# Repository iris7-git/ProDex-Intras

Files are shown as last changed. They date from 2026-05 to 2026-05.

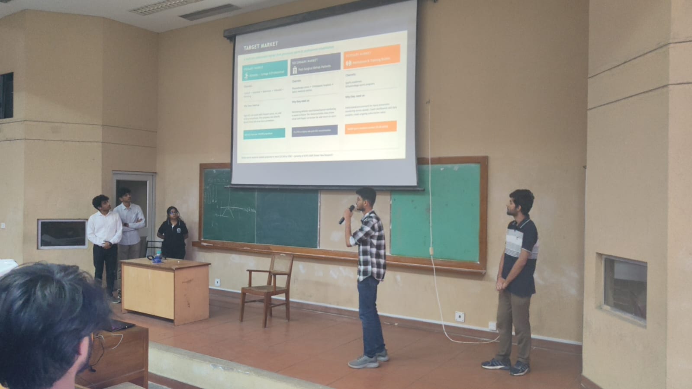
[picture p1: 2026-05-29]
Images/WhatsApp Image 2026-05-28 at 12.59.43 PM (2).jpeg

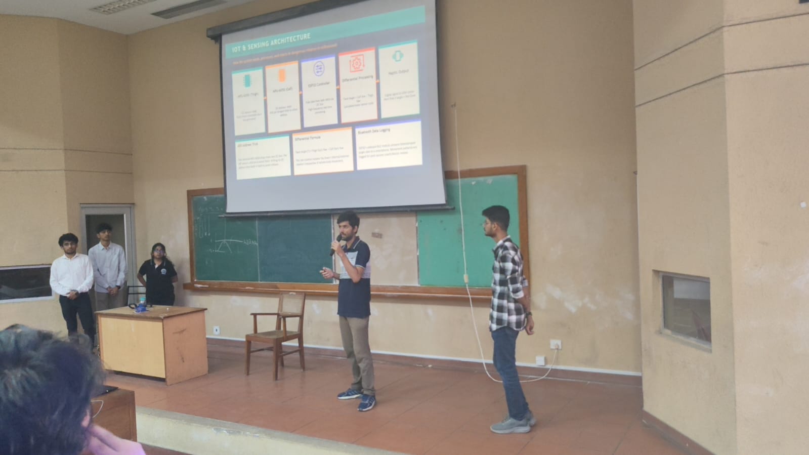
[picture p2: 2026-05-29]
Images/WhatsApp Image 2026-05-28 at 12.59.47 PM (1).jpeg

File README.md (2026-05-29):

# PivotPoint — Real-Time ACL Injury Prevention System

> A smart wearable brace that detects dangerous knee rotation in real-time and delivers instant haptic warnings to prevent ACL injuries before they happen.

---

## The Problem

ACL injuries occur when the knee twists too far, too fast — typically during landings or pivots. The critical issue: **there is no warning**. Standard braces provide mechanical support but cannot detect the hidden rotational torque that causes ligament rupture, leaving athletes moving in high-risk positions with no feedback.

---

## Solution Overview

PivotPoint combines a **mechanical support frame** and an **IoT monitoring system** into a single wearable device.

### Part 1 — Mechanical Frame

An external skeleton that stabilizes the knee joint without restricting natural athletic movement.

| Component | Function |
|---|---|
| **Dual Tapered Cuffs** (Thigh + Calf) | Conform to leg geometry; prevent slipping during dynamic movement |
| **Aluminum Lateral Rods** | Rigid side-rails anchored to thigh and calf cuffs via bolted slots |
| **Sliding-Slot Kinematic Hinge** | Oval vertical slot on calf rod allows free knee flexion while resisting rotational torque |
| **Revolute Lap-Joint at Knee** | Mimics the knee's primary axis of rotation; metal stiffness resists twisting forces |
| **D-Ring Velcro Strap System** | High-compression lock ensuring the frame stays synced with bone movement |

The rods act as **load-sharing partners** — absorbing a portion of rotational torque that would otherwise be borne entirely by the ACL.

### Part 2 — IoT Monitoring System

| Component | Role |
|---|---|
| **ESP32 Microcontroller** | Central processing unit; pulls sensor data and drives outputs |
| **2× MPU-6050 IMU Sensors** | One in thigh cuff, one in calf cuff; track femur vs. tibia orientation |
| **AD0 Address Offset Wiring** | Allows two identical I2C sensors to share one ESP32 bus |
| **ERM Haptic Vibration Motor** | Embedded against skin; fires when a danger threshold is crossed |
| **Bluetooth Module** | Streams movement data wirelessly for logging and analysis |

**Processing pipeline:**
1. ESP32 reads yaw angles from both MPU-6050s at high frequency
2. Computes **Twist Angle** = difference between thigh and calf rotation (differential yaw)
3. If Twist Angle exceeds the **Red Zone threshold (15°–20° internal rotation)** → PWM signal triggers haptic motor
4. Athlete feels sharp vibration → corrects form before ACL reaches failure point

---

## Key Features

- **Real-Time Differential Processing** — Twist angle computed on-device; no cloud dependency
- **Haptic Biofeedback Alert** — Instant tactile warning at the danger threshold
- **Kinematic Sliding-Slot Hinge** — Full knee flexion preserved while rotational torque is resisted
- **Dual-Node IMU Array** — Independent tracking of femur and tibia segments
- **Load-Sharing Frame** — Physically absorbs mechanical stress to reduce ligament load
- **Bluetooth Data Logging** — Transmits biomechanical data to smartphone for coach/doctor review

---

## Hardware & Cost

| Category | Component | Cost (Est.) |
|---|---|---|
| Microcontroller & Sensors | ESP32 + 2× MPU-6050 | ₹800 |
| Haptic Feedback | ERM Coin Vibration Motor + MOSFET Driver | ₹150 |
| Power Supply | 3.7V Li-ion Battery + Slide Switch | ₹100 |
| Wearable Base | Compression Knee Sleeve | ₹450 |
| Structural Frame | PETG / Nylon / CF-PLA Filament (3D Printed) | ₹300 |
| Fasteners | M4 Shoulder Bolts, Nyloc Nuts, M2/M3 Nylon Screws + Jumper Wires | ₹150 |
| **Total** | | **~₹1,950** |

---

## Tech Stack

- **Firmware:** ESP32 (Arduino / ESP-IDF)
- **Sensors:** MPU-6050 (I2C, AD0 address differentiation)
- **Communication:** Bluetooth (data logging to smartphone)
- **Mechanical:** 3D-printed PETG/Nylon cuffs, aluminum rods, lap-joint hinge
- **Feedback:** ERM haptic motor via PWM

---

## References

- [Mechanism of Non-Contact ACL Injuries](https://pmc.ncbi.nlm.nih.gov/articles/PMC8858885/)
- [Tibial Internal Rotation and ACL Risk](https://pmc.ncbi.nlm.nih.gov/articles/PMC10768481/)
- [Knee Flexion Angles and ACL Injuries](https://www.medrxiv.org/content/10.1101/2025.10.20.25338317v1.full.pdf)
- [Real-Time Monitoring System for ACL Injury Prevention](https://www.researchgate.net/publication/385367697_Design_and_Development_of_a_Real-time_Monitoring_System_for_ACL_Injury_Prevention)
- [ESP32 Programming Guide](https://www.raypcb.com/esp32-programming-circuit/)

---

## Future Work

- **ML-Based Predictive Analytics** — Use Bluetooth-logged biomechanical history to build a personalized movement baseline per athlete, enabling prediction of fatigue-driven injury risk *before* the knee enters a danger zone
- Cloud dashboard for coaches and physiotherapists
- Multi-joint support (ankle integration)

---

## Team

| Name |
|---|
| Harshil Mishra |
| Shreesh Tripathi |
| Bhargavi Deo |
| Nandan Krishna S |
| Kamalnath |

*Developed as part of IntraProdex, IIT Kharagpur.*

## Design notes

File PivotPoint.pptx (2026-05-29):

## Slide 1

Pivot point

Real-Time Rotational Torque Detection & Haptic Warning System

ACL

TEAM MEMBERS

Harshil Mishra
Shreesh Tripathi
Bhargavi Deo
Nandan Krishna S
Kamalnath

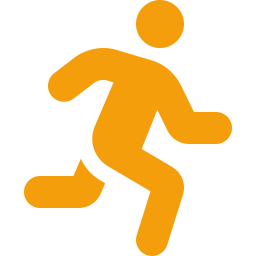
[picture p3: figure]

Intra Prodex

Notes: 1

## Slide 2

PROBLEM STATEMENT

Why are athletes still getting injured despite wearing braces?

How ACL Injuries Happen

  - Knee twists too fast during landing or pivoting
  - Tibial internal rotation exceeds safe threshold
  - Ligament absorbs full torque - then snaps
  - Non-contact injuries are most common (70%+)

The Critical Gap

  - No real-time warning before ligament snaps
  - Twist angle is invisible to the naked eye
  - Traditional braces are purely passive
  - No field-ready monitoring solution exists

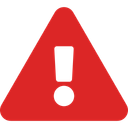
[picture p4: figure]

The Data

  - ₹3–8 Lakh surgery + 9–12 months recovery
  - High recurrence: 15–25% re-injury rate
  - Athletes in football, basketball, badminton most at risk
  - 68.6 ACL tears per 100,000 population in India

Current Braces Are Blind

  - Resist forward movement, not hidden rotation
  - No sensors to detect rotational torque
  - Cannot trigger any warning in real-time

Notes: 2

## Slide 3

RESEARCH & LITERATURE REVIEW

The scientific foundation of our solution

01

Mechanism of Non-Contact ACL Injuries

PMC · 2022

ACL ruptures predominantly occur through tibial internal rotation combined with knee valgus - NOT direct contact. Landing/pivoting biomechanics are the primary culprit.

Insight: Rotation is the root cause.

02

Tibial Internal Rotation & ACL Strain

PMC · 2024

Excessive tibial internal rotation beyond 15°-20° significantly increases ACL loading. This threshold is measurable via differential IMU readings across the joint.

Insight: Gives us our exact Red Zone threshold (15°–20°) for haptic alerts.

03

Knee Flexion Angles & ACL Injury Risk

medRxiv · 2025

ACL injuries peak at low knee flexion angles (< 30°). Athletes land stiff-legged during fatigue, increasing rotational risk. Real-time feedback can correct this.

Insight: Validates need for in-field, real-time monitoring rather than lab analysis.

04

Design of Real-Time ACL Monitoring System

ResearchGate · 2024

IMU-based systems using ESP32 can achieve sub-100ms response latency for joint angle calculations. Differential processing between two sensors is validated as accurate.

Insight: Confirms our ESP32 + dual MPU-6050 architecture is technically feasible.

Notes: 3

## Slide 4

EXISTING SOLUTIONS & THEIR GAPS

Every current solution fails athletes

Solution

What It Does

Critical Limitation

Conclusion

DonJoy / Breg
Functional Braces

Rigid mechanical frame; limits extreme flexion & extension

100% passive - zero sensor data, cannot detect or warn about hidden rotational torque

Blind to rotation

Vicon Optical
Motion Capture

Sub-millimeter 3D tracking of all joint kinematics via camera arrays

Requires lab setup with multiple cameras. Completely unusable on sports fields or clinics

Lab-only, costs lakhs

Smart Compression
Sleeves (e.g. Athos)

Track general metrics (steps, jump height) via embedded single sensors

No rigid support frame - cannot absorb torque. No differential angle processing or haptic alert

No rigid support, no haptics

Our Dynamic
Knee Ankle Support

Dual IMU + rigid frame + real-time differential processing + haptic biofeedback

Currently requires per-athlete calibration.

Field-ready, real-time, way less cost than our competitors

No existing solution combines mechanical support + real-time sensing + haptic alert in a field-deployable, affordable package.

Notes: 4

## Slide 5

OUR SOLUTION - SYSTEM OVERVIEW

A two-part system: physical protection with technological integration

PART 1 - MECHANICAL FRAME

Dual Cuff Frame

Tapered thigh + calf cuffs for secure fit

Aluminum Rods

Lateral rigid rods absorb rotational torque

Revolute Hinge

Lap-joint pin mirrors knee's natural rotation axis

Sliding Slot

Calf rod slot allows free bending, resists twist

Strap System

D-Ring Velcro locks frame to bone movement

PART 2 - IoT MONITORING BRAIN

Dual MPU-6050 IMU Array

One sensor on thigh, one on calf

ESP32 Controller

Pulls data from both IMUs, calculates parameters

Differential Processing

Based on Thigh rotation & Calf rotation

Haptic Alert

ERM motor fires when angle > Red Zone

Bluetooth Logging

Streams movement data to smartphone/coach app

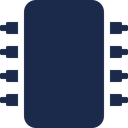
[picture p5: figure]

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
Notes: 5

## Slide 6

MECHANICAL DESIGN

External skeleton engineered to protect without restricting natural athletic movement

Dual Tapered Cuff Frame

Two cuffs (Thigh & Calf) shaped wider at top, narrower at base - mirroring leg anatomy for anti-slip fit. Prevents the brace from sliding during dynamic movement.

Lateral Aluminum Rods

Rigid rods mounted on the lateral (outer) side. Thigh rod fixed via two bolts for a solid femoral anchor. Calf rod secured through a sliding oval slot.

Revolute Hinge (Lap Joint)

Two rods joined at the knee via a lapped pin joint, mimicking the knee's primary flexion axis. Metal stiffness resists the twisting forces that cause ACL tears.

Kinematic Sliding Slot

The calf rod's bolt sits in a vertical oval slot - allows free knee bending (flexion) while maintaining constant lateral and rotational guidance of the lower leg.

D-Ring Velcro Strap System

Loop-back Velcro straps threaded through integrated D-ring slots. Creates high-pressure compression lock ensuring sensors stay perfectly synced with bone movement.

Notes: 6

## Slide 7

IOT & SENSING ARCHITECTURE

How the system reads, processes, and reacts to dangerous rotation in milliseconds

MPU-6050 (Thigh)

I2C Address: 0x68
Tracks femur orientation via 6-axis gyro+accel

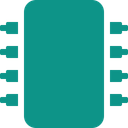
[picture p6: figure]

MPU-6050 (Calf)

I2C Address: 0x69
AD0 pin bridged HIGH to offset address

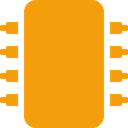
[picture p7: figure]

ESP32 Controller

Pulls data from both IMUs via I2C bus
High-frequency real-time processing

Differential Processing

Twist Angle = Calf Yaw − Thigh Yaw
Calculated every sensor cycle

Haptic Output

Digital signal to ERM motor
Alert fires if angle > Red Zone

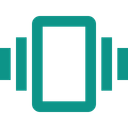
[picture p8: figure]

▶

▶

▶

▶

AD0 Address Trick

Two identical MPU-6050 chips share one I2C bus. The calf sensor's AD0 pin is wired HIGH, shifting its I2C address from 0x68 → 0x69 to avoid collision.

Differential Formula

Twist Angle (°) = Thigh Gyro Yaw − Calf Gyro Yaw
This net rotation isolates the knee's internal/external rotation irrespective of whole-body movement.

Bluetooth Data Logging

ESP32's onboard BLE module streams timestamped angle data to a smartphone. Movement patterns are logged for post-session coach/doctor review.

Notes: 7

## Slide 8

HAPTIC FEEDBACK LOOP

From dangerous angle to corrective warning

SAFE ZONE (0°–15°)

WARNING (15°–20°)

RED ZONE (>20°) - ALERT FIRES

Athlete Pivots

During a landing or cut, the knee begins rotating. Both MPU-6050 sensors capture real-time orientation data independently.

01

ESP32 Calculates Twist Angle

The controller subtracts calf yaw from thigh yaw to compute the exact internal rotation of the knee joint in real time.

02

Red Zone Threshold Crossed

If the differential angle exceeds 15°-20°, the ESP32 identifies a high-risk event. A trigger signal is generated.

03

ERM Motor Fires

The embedded Eccentric Rotating Mass vibration motor activates, delivering a sharp tactile pulse directly against the athlete's skin.

04

Athlete Self-Corrects

The physical sensation is an instant reflex trigger. The athlete adjusts stance or landing mechanics before reaching ligament failure threshold.

05

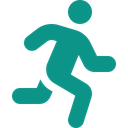
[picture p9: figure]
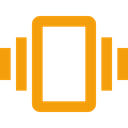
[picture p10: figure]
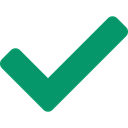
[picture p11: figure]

→

→

→

→

Vibration alert is instantaneous; the athlete feels it before the ligament reaches its mechanical failure point.

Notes: 8

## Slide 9

KEY FEATURES SUMMARY

6 integrated features that set the Dynamic Knee Ankle Support apart

Kinematic Sliding Slot

Oval slot on calf rod, free bending, constant rotational resistance

Dual-Node IMU Array

Two MPU-6050s track femur vs. tibia orientation independently

Real-Time ESP32 Processing

High-frequency on-device computation

Haptic Biofeedback Alert

Instant tactile pulse when knee enters dangerous Red Zone

Load-Sharing Mitigation

Rigid frame absorbs mechanical stress alongside the ligament

Bluetooth Data Logging

Streams movement patterns wirelessly to coach/doctor app

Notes: 9

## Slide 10

COST ANALYSIS

A ₹1,950 solution vs. alternatives

Category

Component

Cost

Cost Comparison vs. Alternatives

Microcontroller & Sensors

ESP32 + 2× MPU-6050 IMU

₹800

Vicon Motion Capture

₹20–50 Lakh

Haptic Feedback

ERM Vibration Motor + Driver

₹150

Power Supply

3.3V Li-ion Battery + Switch

₹100

DonJoy Brace

₹5,000–15,000

Wearable Base

Compression Knee Sleeve

₹450

3D Printed Frame

PETG / Nylon / CF-PLA Filament

₹300

Smart Sleeves

₹3,000–8,000

Mechanical Fasteners

M4 Shoulder Bolts + Nyloc Nuts

₹150

Our Solution

Wiring & Misc

Jumper Wires, connectors

₹0

₹1,950

TOTAL ESTIMATED COST

~₹1,950

At ₹1,950, our device is 2.5–8× cheaper than passive-only braces, and over 1,000× cheaper than lab systems.

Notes: 10

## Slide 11

TARGET MARKET

A multi-tier addressable market from grassroots sports to professional rehabilitation

PRIMARY MARKET

Athletes — College & Professional

Channels:

Football • Basketball • Badminton • Volleyball • Wrestling

Why they need us:

High-ACL-risk sports with frequent pivot, cut, and landing movements. First adopters who directly benefit from real-time injury prevention.

68.6 ACL tears per 100,000 population

SECONDARY MARKET

Post-Surgical Rehab Patients

Channels:

Physiotherapy clinics • Orthopaedic hospitals • Sports medicine centres

Why they need us:

Recovering athletes need biomechanical monitoring to avoid re-injury. Our device provides data-driven rehab with haptic correction for safe return-to-sport.

15–25% re-injury rate post-ACL reconstruction

TERTIARY MARKET

Institutions & Training Bodies

Channels:

Sports academies
School/college sports programs

Why they need us:

Institutional procurement for injury prevention monitoring across squads. Coach dashboards and data analytics create ongoing subscription value.

Global sports medicine market: $9.2B (2024)

Global sports medicine market projected to reach $15.3B by 2030 — growing at 6.5% CAGR (Grand View Research)

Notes: 11

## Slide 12

RISKS & LIMITATIONS

Transparent risk assessment - and our mitigation roadmap for each

Sensor Drift Over Time

Gyroscope bias accumulates → angle readings become inaccurate after extended use.

Periodic re-calibration protocol + drift-correction algorithm in firmware.

Risk:

Comfort

Rigid frame may cause discomfort in long matches; athletes may remove brace.

Comfortable padding, lightweight materials, comfort-testing iterations.

Risk:

Per-Athlete Calibration

Each user requires individual calibration for accurate Red Zone thresholds.

Auto-calibration routine on first use; ML-based adaptive baseline.

Risk:

Mitigation:

Mitigation:

Mitigation:

Not a Medical Replacement

Device is a warning system — cannot prevent all injuries or replace clinical assessment.

Clear usage guidelines + medical professional integration in dashboard.

Regulatory Pathway

Medical device clearance required before clinical or commercial deployment.

Plan: Start as sports training aid

Battery Life Constraints

3.3V Li-ion battery limits continuous operation — replacement/recharging during matches.

Low-power ESP32 sleep modes; wireless charging coil integration planned.

Risk:

Risk:

Risk:

Mitigation:

Mitigation:

Mitigation:

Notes: 12

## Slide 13

FUTURE PROSPECTS

The roadmap from prototype to AI-powered sports safety platform

ML & Predictive Analytics

Leveraging Bluetooth-logged biomechanical data, machine learning models will learn each athlete's unique movement patterns and establish personalized baselines. The system will predict fatigue-related injury risk BEFORE kinematics enter the danger zone.

Personalized Fatigue-Risk Baselines

Each athlete's 'normal' rotation profile varies. Adaptive calibration will auto-adjust Red Zone thresholds based on individual biomechanics, sport type, and real-time fatigue levels detected from gait pattern degradation.

ML on ESP32

Anomaly detection

Long-term pattern learning

Adaptive thresholds

Fatigue modelling

Sport-specific profiles

Miniaturisation & Wireless Charging

Replacing current components with miniaturized alternatives and integrating a wireless charging coil will reduce device weight by 40%+. Form factor will shrink to a discreet sensor patch worn beneath athletic gear.

Coach & Doctor Dashboard App

A cross-platform mobile/web app providing coaches and physiotherapists with real-time biomechanical dashboards, session reports, injury risk heatmaps, and long-term trend analysis for entire squads.

miniaturization

wireless charging

Sub weight

App

Squad analytics

Injury risk heatmaps

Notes: 13

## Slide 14

THANK YOU

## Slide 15

APPENDIX - Circuit Diagram & Visual representation

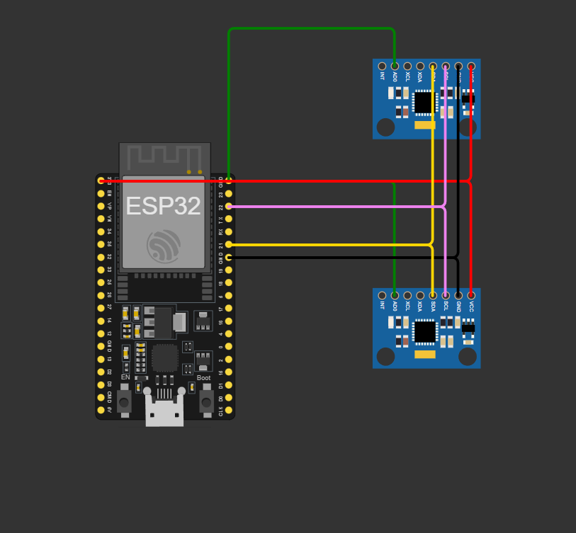
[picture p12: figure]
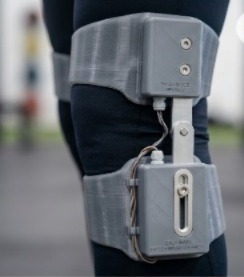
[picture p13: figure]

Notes: 14

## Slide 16

APPENDIX – CAD & References

Mechanism of non contact ACL injuries (https://pmc.ncbi.nlm.nih.gov/articles/PMC8858885/)
PMC · 2022
Tibial internal rotation (https://pmc.ncbi.nlm.nih.gov/articles/PMC10768481/)
PMC · 2024
Relation of (https://www.medrxiv.org/content/10.1101/2025.10.20.25338317v1.full.pdf)Kneeflexion (https://www.medrxiv.org/content/10.1101/2025.10.20.25338317v1.full.pdf) angles with ACL injuries (https://www.medrxiv.org/content/10.1101/2025.10.20.25338317v1.full.pdf)
medRxiv · 2025
Design and Development of a Real-time Monitoring System for ACL Injury Prevention (https://www.researchgate.net/publication/385367697_Design_and_Development_of_a_Real-time_Monitoring_System_for_ACL_Injury_Prevention)
ResearchGate · 2024
ESP32 programming guide (https://www.raypcb.com/esp32-programming-circuit/)

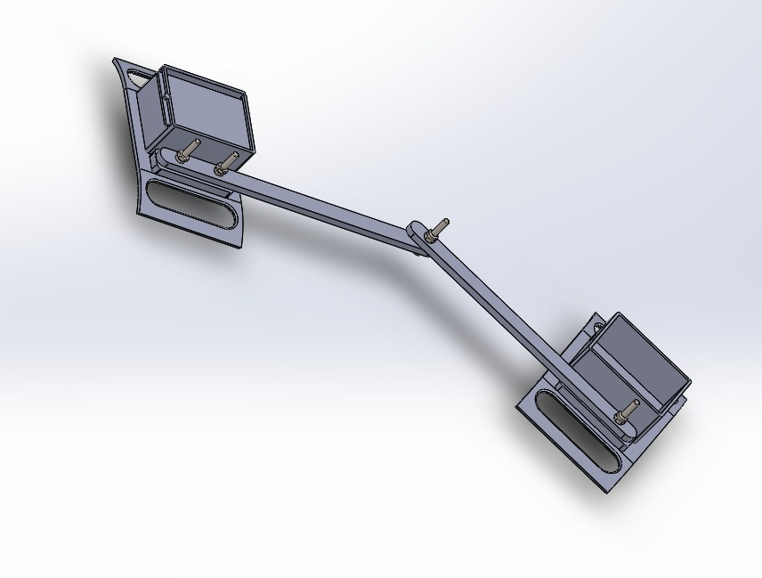
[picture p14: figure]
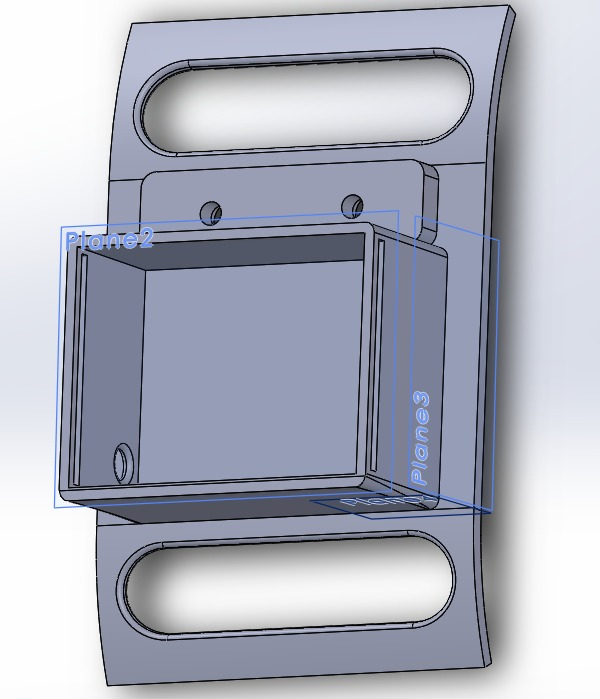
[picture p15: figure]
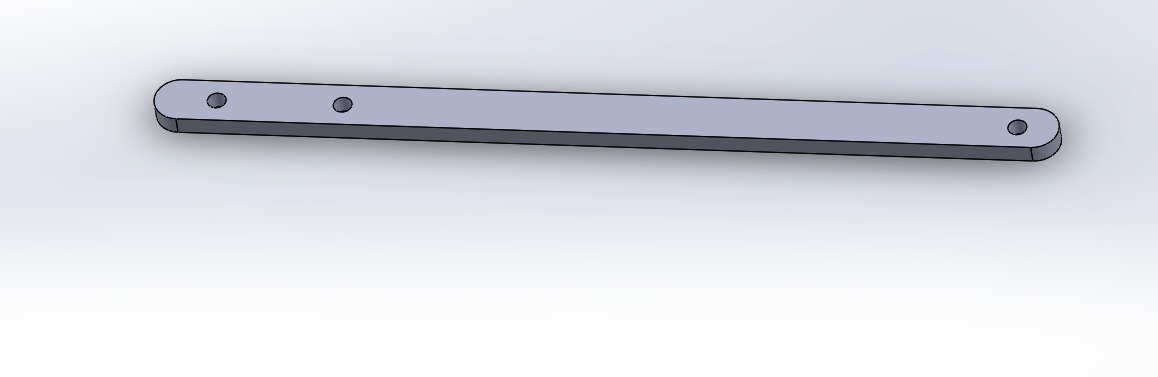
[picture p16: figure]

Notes: 15

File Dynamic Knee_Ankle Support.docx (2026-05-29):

# PivotPoint

## Team Members

- Harshil Mishra
- Shreesh Tripathi
- Bhargavi Deo
- Nandan Krishna S
- Kamalnath

# Understanding of the Problem

ACL(Anterior Cruciate Ligament) injuries usually happen when the knee twists too far and too fast while an athlete is landing or turning. Right now, there is no way for a person to know if their leg is twisting at a dangerous angle until the ligament actually snaps. Standard knee braces can hold the leg straight, but they cannot measure or see the hidden twist that causes the most damage. This leaves athletes moving in high-risk ways without any warning or data to stop an injury before it happens

## Relevant Literature

Mechanism of non contact ACL injuries (https://pmc.ncbi.nlm.nih.gov/articles/PMC8858885/)

Tibial internal rotation (https://pmc.ncbi.nlm.nih.gov/articles/PMC10768481/)

Relation of Kneeflexion angles with ACL injuries (https://www.medrxiv.org/content/10.1101/2025.10.20.25338317v1.full.pdf)

Design and Development of a Real-time Monitoring System for ACL Injury Prevention (https://www.researchgate.net/publication/385367697_Design_and_Development_of_a_Real-time_Monitoring_System_for_ACL_Injury_Prevention)

ESP32 programming guide (https://www.raypcb.com/esp32-programming-circuit/)

## Existing Solutions

1. Traditional Prophylactic/Functional Braces (e.g., DonJoy, Breg):

- Drawback: These are entirely passive, relying solely on rigid mechanical structures to restrict or lock movement.
- Result: While they offer lateral stability, they cannot measure hidden twisting forces, dynamically warn the user, and ultimately can only resist force until the point of mechanical failure.

2. Optical Motion Capture Systems (e.g., Vicon):

- Drawback: These systems require multiple cameras and post-processing, confining them strictly to laboratory settings and their cost is over the roof.
- Result: Although they provide sub-millimeter tracking of knee kinematics, they are useless for real-time field applications or live injury mitigation.

3. Smart Compression Sleeves:

- Drawback: These modern wearables track general metrics (like step count or jump height) with single sensors but crucially lack a rigid mechanical support frame needed to absorb rotational torque.
- Result: They cannot process differential joint angles to trigger the instant haptic warnings required for effective injury prevention.

# Proposed Solution

The Proposed Solution consists of two parts:

### Part 1: The Mechanical Part (The Support and Mitigation Frame) -

The hardware is designed to act as an external skeleton that stabilizes the joint without restricting natural athletic movement.
a) Supportive Mitigation: The rigid rods are not intended to lock the knee in a frozen position. Instead, they provide a support system that absorbs a portion of the rotational torque that would otherwise be handled entirely by the ACL. By sharing the load between the metal frame and the ligament, the system reduces the overall risk of a rupture during high-stress maneuvers.

b) Dual-Cuff Frame: The system uses two tapered cuffs (Thigh and Calf). Both are wider at the top and narrower at the bottom to match the leg’s natural shape. This ensures the brace doesn't slip down, keeping the support structure aligned with the knee joint at all times.

c)The Aluminum Sticks: Rigid aluminum rods are mounted on the outside (lateral side) of the leg.

- Thigh Side: The rod is fixed with two bolts into the thigh box. This creates a solid anchor point against the femur.
- Calf Side: The rod is secured by a bolt sitting in a vertical sliding slot. This allows the leg to bend (flexion) while the rod provides lateral and rotational guidance to the lower leg.

d) The Revolute Hinge: The two rods are joined at the knee using a lap joint (two sticks pinned together). This mimic's the knee's primary axis of rotation while the metal's stiffness resists the twisting forces that lead to injury.

e) Strap System (to connect cuff with leg): Each cuff uses D-Ring Velcro straps threaded through integrated slots. This creates a high-pressure lock to the limb, ensuring the mechanical frame and the sensors stay perfectly synced with the athlete's bones.

### Part 2: The IoT System (The Monitoring & Warning Brain)

a) Two Sensors used - Two IMU (Inertial Measurement Unit) Sensors are used. One is placed inside the rectangular hollow box in the thigh cuff and the other in the calf cuff.

b) Real-Time Differential Processing: The ESP32 pulls data from both sensors. It calculates the Twist Angle (the difference between the thigh and calf rotation).

c) Haptic Biofeedback: A small ERM (Eccentric Rotating Mass) haptic motor is embedded inside the cuff, sitting directly against the athlete's skin.

- The Trigger: When the ESP32 detects that the rotational torque or angle is entering a Red Zone (e.g., above 15°–20° of internal rotation), it sends a PWM signal to the motor.
- The Result: The athlete feels a sharp vibration on their leg. This instant physical cue tells them to adjust their landing or pivot, allowing them to correct their form before the ligament reaches its breaking point.

## Key Features of the Proposed Model:

1. Kinematic Sliding-Slot Hinge: Features a vertical oval slot on the calf rod to allow free knee bending while maintaining constant lateral and rotational support.
2. D-Ring Strapping: Utilizes a loop-back Velcro system through integrated slots to provide maximum compression and "lock" the sensors to bone movement.
3. Dual-Node IMU Array: Integrates two MPU-6050 sensors to track the orientation of the femur versus the tibia for precise twist-angle calculation.
4. AD0 Address Offset: Uses a custom wiring bridge on the calf sensor's AD0 pin to allow two identical I2C devices to communicate with one ESP32.
5. Real-Time ESP32 Processing: Processes high-frequency movement data internally to detect sudden, high-risk pivots or landing impacts as they happen.
6. Haptic Biofeedback Alert: Triggers an embedded vibration motor to provide an instant tactile warning when the knee enters a dangerous rotational "Red Zone."
7. Load-Sharing Risk Mitigation: Acts as a physical safety net that absorbs a portion of the mechanical stress to reduce the risk of ligament failure.
8. Bluetooth Data Logging: Transmits movement patterns wirelessly to a smartphone for long-term biomechanical analysis by coaches or doctors.

## Cost Analysis of our product:

Category | Component | Estimated cost
Microcontroller & Sensors | ESP32 Microcontroller | ₹ 800
| MPU-6050 IMU Sensors (2 units)
Haptic Feedback | 10mm Flat Coin Vibration Motor | ₹ 150
| Vibration Motor Driver Module (MOSFET type)
Power Supply | 3.7V Li ion Battery (Rechargeable) | ₹ 100
| Mini SPDT Slide Switch
Wearable Base & Comfort | Compression Knee Sleeve | ₹ 450
Structural Frame (3D Printed) | High-Strength Filament (PETG, Nylon, or CF PLA) | ₹ 300
Mechanical Fasteners | M4 Steel Shoulder Bolts and Nyloc Nuts | ₹ 150
| M2/M3 Nylon Screws
Wiring | Jumper Wires
Total Estimated Cost | | ~ ₹ 1,950

## Future Prospects:

Machine Learning and Predictive Analytics:

Leveraging the system's current Bluetooth data logging functionality, future development will incorporate machine learning and predictive analytics. These algorithms will process extensive historical biomechanical data to analyze an athlete's unique long-term movement patterns, thereby establishing a personalized baseline. This will enable the system to anticipate and predict fatigue-related injury risks before the kinematics deviate into an immediate danger zone.

## Diagram:

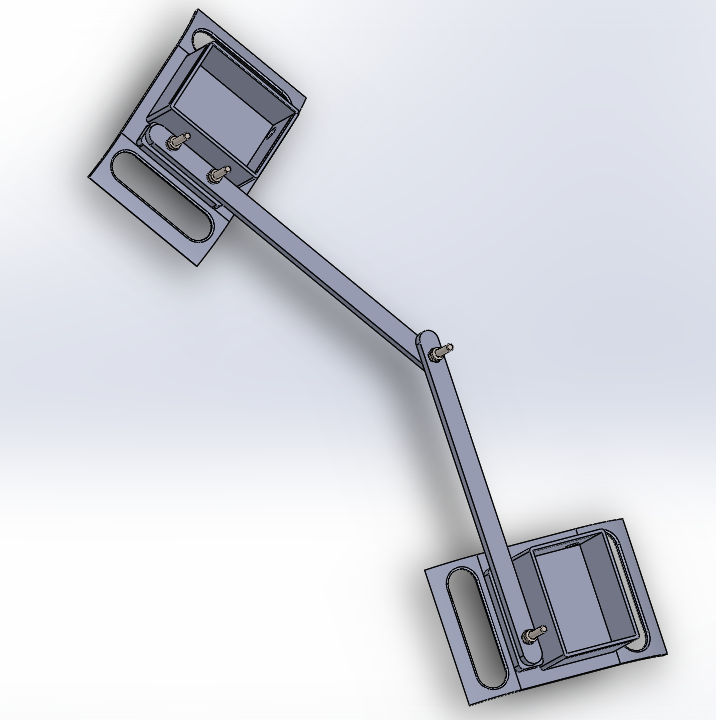
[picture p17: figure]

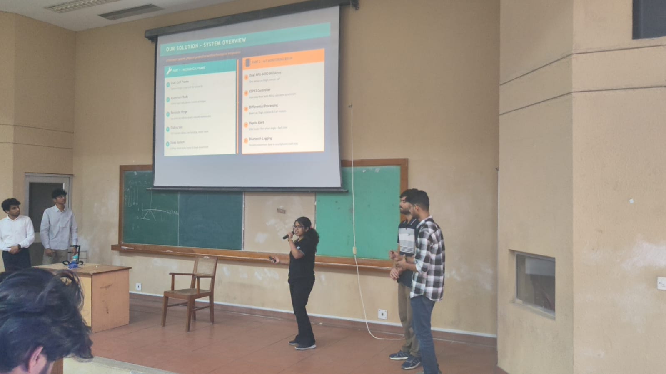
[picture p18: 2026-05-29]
Images/WhatsApp Image 2026-05-28 at 12.59.48 PM.jpeg

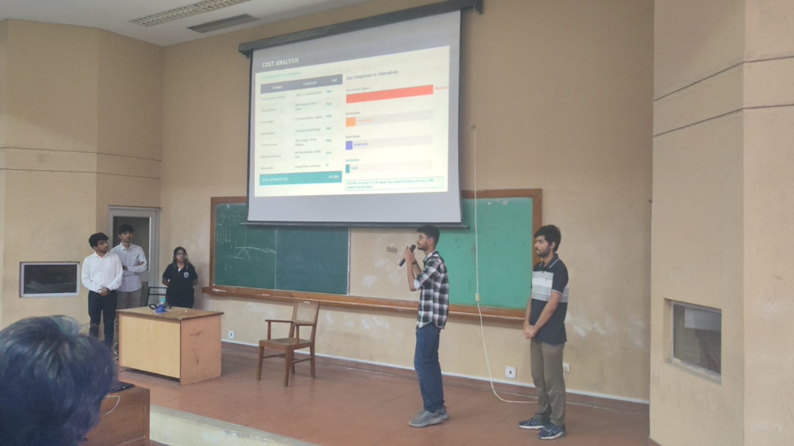
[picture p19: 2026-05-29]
Images/WhatsApp Image 2026-05-28 at 12.59.46 PM.jpeg

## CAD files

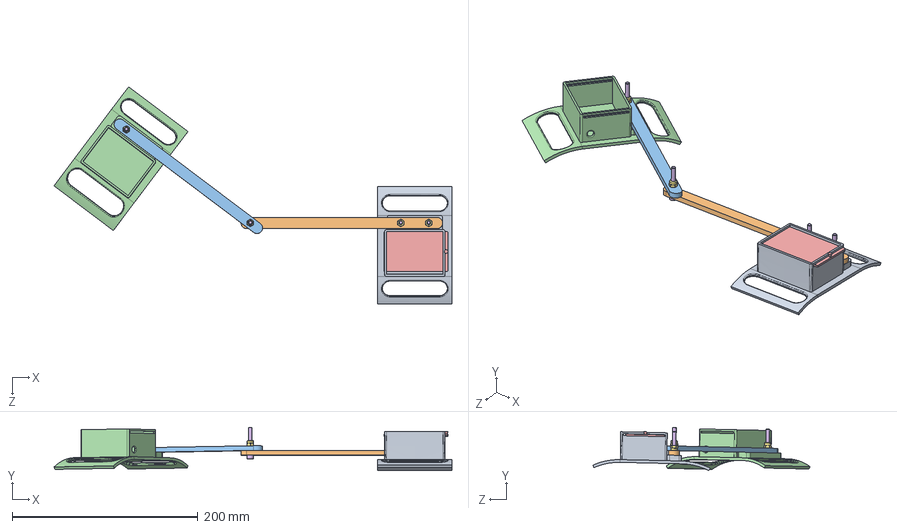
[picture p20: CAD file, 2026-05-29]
Assem3.SLDASM
428.3 x 46.6 x 233.9 mm
Thigh Box
Thigh Rod
Calf Rod
Calf Box
Lid for calf box and thigh box
socket head cap screw_iso-final x 4
torque nut 01_iso x 4

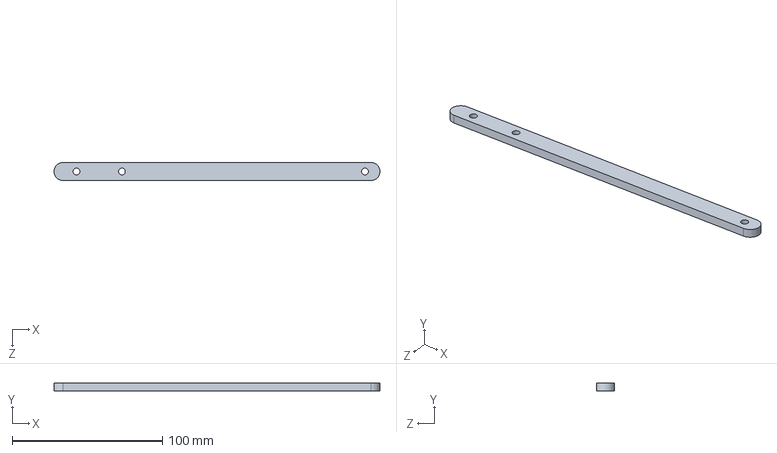
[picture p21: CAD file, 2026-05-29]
CAD Assembly Parts/Thigh Rod.SLDPRT
216.9 x 5.00 x 12.0 mm

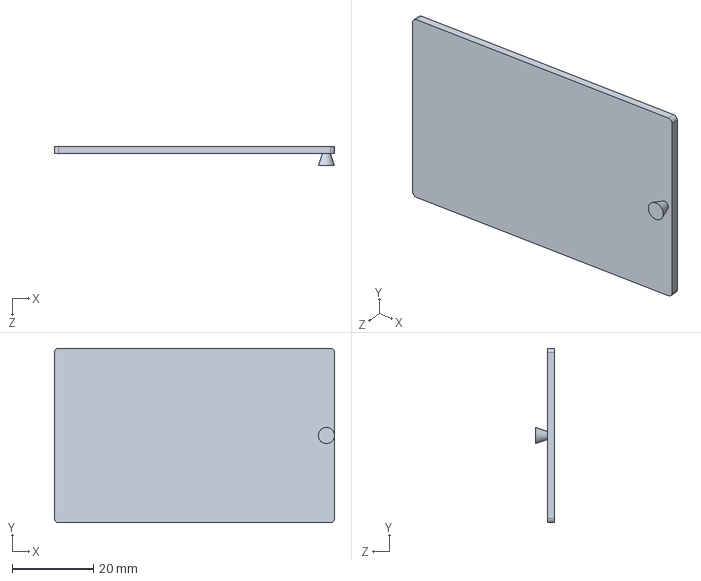
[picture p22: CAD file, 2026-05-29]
CAD Assembly Parts/Lid for calf box and thigh box.SLDPRT
69.0 x 43.0 x 4.80 mm

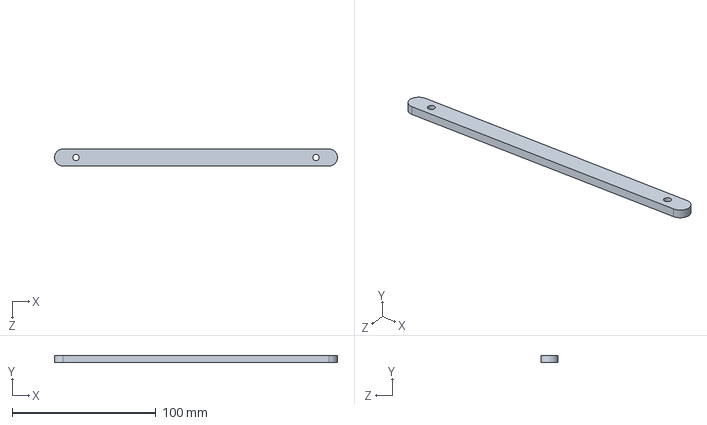
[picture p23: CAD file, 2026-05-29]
CAD Assembly Parts/Calf Rod.SLDPRT
197.0 x 5.00 x 12.0 mm

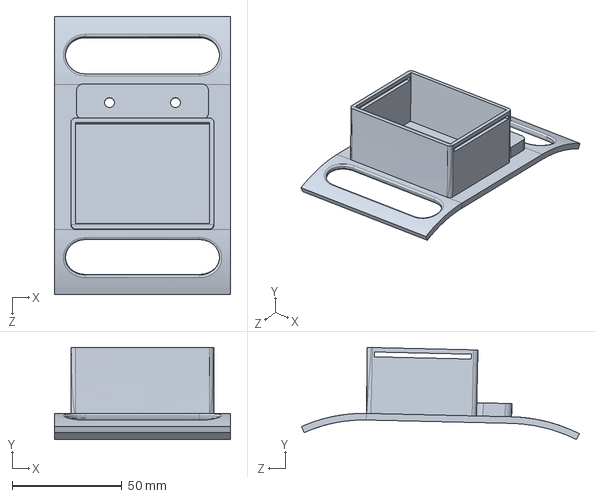
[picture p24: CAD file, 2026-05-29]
CAD Assembly Parts/Thigh Box.SLDPRT
80.0 x 41.9 x 126.4 mm

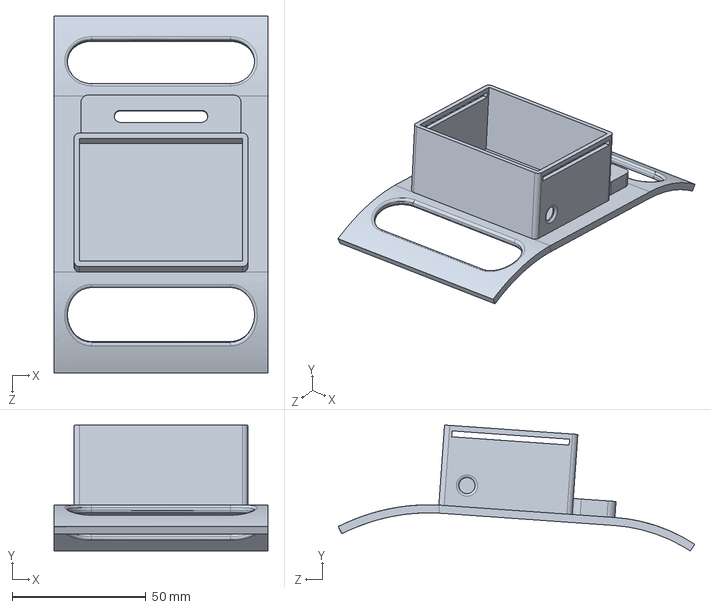
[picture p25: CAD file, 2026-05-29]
CAD Assembly Parts/Calf Box.SLDPRT
80.0 x 47.1 x 133.3 mm

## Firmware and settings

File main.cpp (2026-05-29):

#include <Wire.h>
#include <Adafruit_MPU6050.h>
#include <Adafruit_Sensor.h>
#include <WiFi.h>
#include <WebServer.h>

// ---------------------------------------------------------
// HARDWARE SETTINGS
// ---------------------------------------------------------
#define MOTOR_PIN 15

// ---------------------------------------------------------
// WIFI SETTINGS
// Set these to your phone hotspot credentials.
// After boot, Serial prints the IP — open it in any browser.
// ---------------------------------------------------------
const char* WIFI_SSID     = "IQOO Z10X";
const char* WIFI_PASSWORD = "iznhkdj94reqtzm";

// ---------------------------------------------------------
// CALIBRATION SETTINGS
// ---------------------------------------------------------
#define CALIB_DURATION_MS        3000
#define CALIB_SAMPLE_INTERVAL_MS 10

// ---------------------------------------------------------
// THRESHOLDS — 3 zones per metric
// YELLOW = warning (approaching danger)
// RED    = alert (dangerous, haptic fires)
// ---------------------------------------------------------

// Knee Flexion/Extension
const float HYPEREXTENSION_RED    = -5.0;   // degrees
const float FLEXION_YELLOW        = 110.0;  // degrees
const float FLEXION_RED           = 130.0;  // degrees

// Valgus Wobble
const float WOBBLE_YELLOW         = 10.0;   // degrees
const float WOBBLE_RED            = 15.0;   // degrees

// Tibial Twist
const float TWIST_YELLOW          = 12.0;   // degrees
const float TWIST_RED             = 20.0;   // degrees

// Hard Landing
const float IMPACT_RED            = 29.4;   // m/s² net (~3G)

// Combined mechanics — all three at medium threshold = critical
const float COMBO_ANGLE_THRESH    = 20.0;
const float COMBO_WOBBLE_THRESH   = 8.0;
const float COMBO_TWIST_THRESH    = 10.0;

// ---------------------------------------------------------
// SIDE-MOUNT AXIS NOTE
// MPUs mounted on the SIDE of thigh and shin:
//   Knee Flexion/Extension -> gyro.y / accel Y-axis
//   Valgus/Varus Wobble    -> gyro.x / accel X-axis
//   Tibial Twist (Yaw)     -> gyro.z
// Swap gyro.x <-> gyro.y if physical test shows mismatch.
// ---------------------------------------------------------

// ---------------------------------------------------------
// WiFi / WEB SERVER GLOBALS
// ---------------------------------------------------------
WebServer server(80);

// Simple ring buffer to store last 30 alert events
// Each entry is a plain string — readable in the browser
#define MAX_LOG_ENTRIES 30
String  alertLog[MAX_LOG_ENTRIES];
int     logHead    = 0;   // points to next write position
int     logCount   = 0;   // total entries written so far
unsigned long alertCounter = 0;

// ---------------------------------------------------------
// IMU & FILTER GLOBALS
// ---------------------------------------------------------
Adafruit_MPU6050 thighIMU;
Adafruit_MPU6050 calfIMU;

unsigned long lastTime = 0;
float alpha = 0.98;

float thighPitch = 0, thighRoll = 0;
float calfPitch  = 0, calfRoll  = 0;
float relTwist   = 0;

float biasPitchThigh = 0, biasRollThigh = 0;
float biasPitchCalf  = 0, biasRollCalf  = 0;
float biasGyroZ      = 0;

// ---------------------------------------------------------
// FUNCTION DECLARATIONS
// ---------------------------------------------------------
void triggerHaptic(int pattern);
void calibrate();
void setupWiFi();
void setupWebServer();
void logAlert(const char* zone, const char* alertType,
              float angle, float wobble,
              float twist, float impact);

// ---------------------------------------------------------
// WEB PAGE
// Auto-refreshes every 3 seconds.
// Shows all stored alert events in a clean table.
// ---------------------------------------------------------
void handleRoot() {
  String html = R"rawhtml(
<!DOCTYPE html><html><head>
<meta charset='UTF-8'>
<meta http-equiv='refresh' content='3'>
<meta name='viewport' content='width=device-width, initial-scale=1'>
<title>ACL Brace Monitor</title>
<style>
  body { font-family: monospace; background: #0d0d0d; color: #e0e0e0; padding: 16px; }
  h2   { color: #00e5ff; margin-bottom: 4px; }
  p    { color: #888; font-size: 12px; margin-top: 0; }
  table { width: 100%; border-collapse: collapse; font-size: 13px; }
  th   { background: #1a1a1a; color: #00e5ff; padding: 8px; text-align: left; }
  td   { padding: 7px 8px; border-bottom: 1px solid #222; }
  .CRITICAL { color: #ff1744; font-weight: bold; }
  .RED      { color: #ff6d00; }
  .YELLOW   { color: #ffd600; }
  .empty    { color: #555; text-align: center; padding: 24px; }
</style>
</head><body>
<h2>ACL Brace — Alert Log</h2>
<p>Auto-refreshes every 3 seconds &nbsp;|&nbsp; )rawhtml";

  html += String(logCount) + " event(s) recorded</p>";
  html += "<table><tr><th>#</th><th>Zone</th><th>Type</th>"
          "<th>Angle</th><th>Wobble</th><th>Twist</th><th>Impact</th><th>Time(s)</th></tr>";

  if (logCount == 0) {
    html += "<tr><td colspan='8' class='empty'>No alerts yet — system monitoring...</td></tr>";
  } else {
    // Print newest first
    int entries = min(logCount, MAX_LOG_ENTRIES);
    for (int i = 0; i < entries; i++) {
      int idx = (logHead - 1 - i + MAX_LOG_ENTRIES) % MAX_LOG_ENTRIES;
      html += alertLog[idx];
    }
  }

  html += "</table></body></html>";
  server.send(200, "text/html", html);
}

// ---------------------------------------------------------
// SETUP
// ---------------------------------------------------------
void setup() {
  Serial.begin(115200);
  delay(2000);

  pinMode(MOTOR_PIN, OUTPUT);
  digitalWrite(MOTOR_PIN, LOW);

  Serial.println("\n--- Smart ACL Brace: Full Kinematics + WiFi Mode ---");

  // --- Step 1: IMUs ---
  Wire.begin(21, 22);
  Wire.setClock(100000);
  Wire.setTimeOut(150);

  Serial.println("Checking Thigh Sensor (0x68)...");
  if (!thighIMU.begin(0x68)) {
    Serial.println("CRITICAL ERROR: Thigh MPU6050 not found. HALTING.");
    while (true) { delay(1000); }
  }
  Serial.println("Thigh Sensor OK!");

  Serial.println("Checking Calf Sensor (0x69)...");
  if (!calfIMU.begin(0x69)) {
    Serial.println("CRITICAL ERROR: Calf MPU6050 not found. Is AD0 on 3.3V? HALTING.");
    while (true) { delay(1000); }
  }
  Serial.println("Calf Sensor OK!");

  thighIMU.setAccelerometerRange(MPU6050_RANGE_8_G);
  thighIMU.setGyroRange(MPU6050_RANGE_500_DEG);
  calfIMU.setAccelerometerRange(MPU6050_RANGE_8_G);
  calfIMU.setGyroRange(MPU6050_RANGE_500_DEG);

  // --- Step 2: WiFi + Web Server ---
  setupWiFi();
  setupWebServer();

  // --- Step 3: Calibrate ---
  triggerHaptic(5); // 2 short buzzes: "hold still"

  Serial.print("Calibrating for ");
  Serial.print(CALIB_DURATION_MS / 1000);
  Serial.println(" seconds... Hold still in neutral stance.");

  calibrate();

  triggerHaptic(1); // 1 long buzz: "done, go"
  Serial.println("System Running.");
  Serial.println("----------------------------------------------------");

  lastTime = millis();
}

// ---------------------------------------------------------
// WIFI SETUP
// ---------------------------------------------------------
void setupWiFi() {
  Serial.print("[WiFi] Connecting to ");
  Serial.print(WIFI_SSID);

  WiFi.begin(WIFI_SSID, WIFI_PASSWORD);

  int attempts = 0;
  while (WiFi.status() != WL_CONNECTED && attempts < 20) {
    delay(500);
    Serial.print(".");
    attempts++;
  }

  if (WiFi.status() == WL_CONNECTED) {
    Serial.println("\n[WiFi] Connected!");
    Serial.print("[WiFi] Open this in your browser: http://");
    Serial.println(WiFi.localIP());
  } else {
    // WiFi failed — system still works, just no remote logging
    Serial.println("\n[WiFi] Could not connect. Running Serial-only mode.");
  }
}

// ---------------------------------------------------------
// WEB SERVER SETUP
// ---------------------------------------------------------
void setupWebServer() {
  server.on("/", handleRoot);
  server.begin();
  Serial.println("[Web] Server started on port 80.");
}

// ---------------------------------------------------------
// LOG ALERT
// Stores event in ring buffer AND prints to Serial.
// Zone is "YELLOW" or "RED" or "CRITICAL".
// ---------------------------------------------------------
void logAlert(const char* zone, const char* alertType,
              float angle, float wobble,
              float twist, float impact) {
  alertCounter++;
  float timestamp = millis() / 1000.0;

  // Serial log
  Serial.printf("[%s] #%lu %s | Angle:%.1f Wobble:%.1f Twist:%.1f Impact:%.1f t=%.1fs\n",
    zone, alertCounter, alertType, angle, wobble, twist, impact, timestamp);

  // Build HTML table row for web page
  String row = "<tr class='";
  row += zone;
  row += "'><td>";
  row += alertCounter;
  row += "</td><td>";
  row += zone;
  row += "</td><td>";
  row += alertType;
  row += "</td><td>";
  row += String(angle, 1);
  row += "°</td><td>";
  row += String(wobble, 1);
  row += "°</td><td>";
  row += String(twist, 1);
  row += "°</td><td>";
  row += String(impact, 1);
  row += " m/s²</td><td>";
  row += String(timestamp, 1);
  row += "s</td></tr>";

  // Write to ring buffer
  alertLog[logHead] = row;
  logHead = (logHead + 1) % MAX_LOG_ENTRIES;
  logCount++;
}

// ---------------------------------------------------------
// CALIBRATION
// ---------------------------------------------------------
void calibrate() {
  float accumPitchThigh = 0, accumRollThigh = 0;
  float accumPitchCalf  = 0, accumRollCalf  = 0;
  float accumGyroZ      = 0;
  int   samples         = 0;

  unsigned long calibStart = millis();

  while (millis() - calibStart < CALIB_DURATION_MS) {
    sensors_event_t t_a, t_g, t_temp;
    sensors_event_t c_a, c_g, c_temp;
    thighIMU.getEvent(&t_a, &t_g, &t_temp);
    calfIMU.getEvent(&c_a, &c_g, &c_temp);

    accumPitchThigh += atan2(t_a.acceleration.y, sqrt(pow(t_a.acceleration.x, 2) + pow(t_a.acceleration.z, 2))) * 180.0 / PI;
    accumRollThigh  += atan2(-t_a.acceleration.x, t_a.acceleration.z) * 180.0 / PI;
    accumPitchCalf  += atan2(c_a.acceleration.y, sqrt(pow(c_a.acceleration.x, 2) + pow(c_a.acceleration.z, 2))) * 180.0 / PI;
    accumRollCalf   += atan2(-c_a.acceleration.x, c_a.acceleration.z) * 180.0 / PI;
    accumGyroZ      += (c_g.gyro.z - t_g.gyro.z) * 180.0 / PI;

    samples++;
    delay(CALIB_SAMPLE_INTERVAL_MS);
  }

  biasPitchThigh = accumPitchThigh / samples;
  biasRollThigh  = accumRollThigh  / samples;
  biasPitchCalf  = accumPitchCalf  / samples;
  biasRollCalf   = accumRollCalf   / samples;
  biasGyroZ      = accumGyroZ      / samples;

  thighPitch = biasPitchThigh;
  thighRoll  = biasRollThigh;
  calfPitch  = biasPitchCalf;
  calfRoll   = biasRollCalf;
  relTwist   = 0;

  Serial.print("Bias | thighPitch: "); Serial.print(biasPitchThigh, 2);
  Serial.print("  calfPitch: ");       Serial.print(biasPitchCalf,  2);
  Serial.print("  gyroZ-diff: ");      Serial.print(biasGyroZ,      3);
  Serial.println(" deg/s");

  lastTime = millis();
}

// ---------------------------------------------------------
// MAIN LOOP
// ---------------------------------------------------------
void loop() {
  // Handle incoming web requests (non-blocking)
  server.handleClient();

  // 1. Time Delta
  unsigned long currentTime = millis();
  float dt = (currentTime - lastTime) / 1000.0;
  lastTime = currentTime;

  // 2. Read both sensors
  sensors_event_t t_a, t_g, t_temp;
  sensors_event_t c_a, c_g, c_temp;
  thighIMU.getEvent(&t_a, &t_g, &t_temp);
  calfIMU.getEvent(&c_a, &c_g, &c_temp);

  // 3. Accelerometer tilt (side-mount: Y-axis = knee flexion)
  float t_accelPitch = atan2(t_a.acceleration.y, sqrt(pow(t_a.acceleration.x, 2) + pow(t_a.acceleration.z, 2))) * 180.0 / PI;
  float t_accelRoll  = atan2(-t_a.acceleration.x, t_a.acceleration.z) * 180.0 / PI;
  float c_accelPitch = atan2(c_a.acceleration.y, sqrt(pow(c_a.acceleration.x, 2) + pow(c_a.acceleration.z, 2))) * 180.0 / PI;
  float c_accelRoll  = atan2(-c_a.acceleration.x, c_a.acceleration.z) * 180.0 / PI;

  // 4. Complementary Filter
  thighPitch = alpha * (thighPitch + (t_g.gyro.y * 180.0 / PI) * dt) + (1 - alpha) * t_accelPitch;
  thighRoll  = alpha * (thighRoll  + (t_g.gyro.x * 180.0 / PI) * dt) + (1 - alpha) * t_accelRoll;
  calfPitch  = alpha * (calfPitch  + (c_g.gyro.y * 180.0 / PI) * dt) + (1 - alpha) * c_accelPitch;
  calfRoll   = alpha * (calfRoll   + (c_g.gyro.x * 180.0 / PI) * dt) + (1 - alpha) * c_accelRoll;

  // 5. Relative Tibial Twist — bias-corrected
  float gyroZDelta = ((c_g.gyro.z - t_g.gyro.z) * 180.0 / PI) - biasGyroZ;
  relTwist += gyroZDelta * dt;

  // 6. Kinematic Metrics — relative to calibrated neutral
  float kneeAngle   = (thighPitch - biasPitchThigh) - (calfPitch - biasPitchCalf);
  float wobbleIndex = abs((thighRoll - biasRollThigh) - (calfRoll - biasRollCalf));
  float twistIndex  = abs(relTwist);
  float verticalImpact = abs(c_a.acceleration.z) - 9.8;

  // 7. Danger Logic — CRITICAL > RED > YELLOW, ordered by severity
  bool danger = false;

  // --- CRITICAL: All three mechanisms at once ---
  if (kneeAngle   > COMBO_ANGLE_THRESH &&
      wobbleIndex > COMBO_WOBBLE_THRESH &&
      twistIndex  > COMBO_TWIST_THRESH) {
    Serial.print(">>> CRITICAL: Combined ACL Mechanism! <<<  ");
    logAlert("CRITICAL", "COMBINED", kneeAngle, wobbleIndex, twistIndex, verticalImpact);
    triggerHaptic(4);
    danger = true;
  }

  // --- RED ZONE alerts (haptic fires) ---
  else if (verticalImpact > IMPACT_RED && kneeAngle > 5.0) {
    Serial.print(">>> RED: Hard Landing! <<<  ");
    logAlert("RED", "HARD_LANDING", kneeAngle, wobbleIndex, twistIndex, verticalImpact);
    triggerHaptic(1);
    danger = true;
  }
  else if (kneeAngle < HYPEREXTENSION_RED) {
    Serial.print(">>> RED: Hyperextension! <<<  ");
    logAlert("RED", "HYPEREXTENSION", kneeAngle, wobbleIndex, twistIndex, verticalImpact);
    triggerHaptic(1);
    danger = true;
  }
  else if (kneeAngle > FLEXION_RED) {
    Serial.print(">>> RED: Deep Flexion! <<<  ");
    logAlert("RED", "DEEP_FLEXION", kneeAngle, wobbleIndex, twistIndex, verticalImpact);
    triggerHaptic(2);
    danger = true;
  }
  else if (wobbleIndex > WOBBLE_RED) {
    Serial.print(">>> RED: Valgus Wobble! <<<  ");
    logAlert("RED", "VALGUS_WOBBLE", kneeAngle, wobbleIndex, twistIndex, verticalImpact);
    triggerHaptic(3);
    danger = true;
  }
  else if (twistIndex > TWIST_RED) {
    Serial.print(">>> RED: Tibial Twist! <<<  ");
    logAlert("RED", "TIBIAL_TWIST", kneeAngle, wobbleIndex, twistIndex, verticalImpact);
    triggerHaptic(3);
    danger = true;
  }

  // --- YELLOW ZONE warnings (logged only, no haptic) ---
  else if (kneeAngle > FLEXION_YELLOW) {
    Serial.print(">>> YELLOW: Approaching Deep Flexion <<<  ");
    logAlert("YELLOW", "FLEXION_WARNING", kneeAngle, wobbleIndex, twistIndex, verticalImpact);
    // No haptic — yellow is a caution, not an emergency
  }
  else if (wobbleIndex > WOBBLE_YELLOW) {
    Serial.print(">>> YELLOW: Wobble Warning <<<  ");
    logAlert("YELLOW", "WOBBLE_WARNING", kneeAngle, wobbleIndex, twistIndex, verticalImpact);
  }
  else if (twistIndex > TWIST_YELLOW) {
    Serial.print(">>> YELLOW: Twist Warning <<<  ");
    logAlert("YELLOW", "TWIST_WARNING", kneeAngle, wobbleIndex, twistIndex, verticalImpact);
  }

  // 8. Live Serial Dashboard
  Serial.print("Angle: ");     Serial.print(kneeAngle,      1); Serial.print("deg");
  Serial.print(" | Wobble: "); Serial.print(wobbleIndex,    1); Serial.print("deg");
  Serial.print(" | Twist: ");  Serial.print(twistIndex,     1); Serial.print("deg");
  Serial.print(" | Impact: "); Serial.print(verticalImpact, 1); Serial.println(" m/s2");

  if (danger) { lastTime = millis(); }

  delay(20); // ~50Hz
}

// ---------------------------------------------------------
// HAPTIC FEEDBACK PATTERNS
// Yellow zone has no haptic — it is a log-only caution.
// ---------------------------------------------------------
void triggerHaptic(int pattern) {
  switch (pattern) {

    case 1: // Long single pulse — Hyperextension / Hard Landing
      digitalWrite(MOTOR_PIN, HIGH); delay(500);
      digitalWrite(MOTOR_PIN, LOW);
      break;

    case 2: // Double pulse — Deep Flexion
      digitalWrite(MOTOR_PIN, HIGH); delay(100);
      digitalWrite(MOTOR_PIN, LOW);  delay(100);
      digitalWrite(MOTOR_PIN, HIGH); delay(100);
      digitalWrite(MOTOR_PIN, LOW);
      break;

    case 3: // 3 rapid buzzes — Valgus / Twist
      for (int i = 0; i < 3; i++) {
        digitalWrite(MOTOR_PIN, HIGH); delay(50);
        digitalWrite(MOTOR_PIN, LOW);  delay(50);
      }
      break;

    case 4: // 5 urgent buzzes — Combined Critical
      for (int i = 0; i < 5; i++) {
        digitalWrite(MOTOR_PIN, HIGH); delay(80);
        digitalWrite(MOTOR_PIN, LOW);  delay(40);
      }
      break;

    case 5: // 2 pre-calibration warning buzzes
      for (int i = 0; i < 2; i++) {
        digitalWrite(MOTOR_PIN, HIGH); delay(150);
        digitalWrite(MOTOR_PIN, LOW);  delay(150);
      }
      break;
  }
}

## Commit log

2026-05-29 ppt and cad
    [Assem3.SLDASM]
2026-05-29 assembly parts
    [Calf Box.SLDPRT, Calf Rod.SLDPRT, Lid for calf box and thigh box.SLDPRT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]
